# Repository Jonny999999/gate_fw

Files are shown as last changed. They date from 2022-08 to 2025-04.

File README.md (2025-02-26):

Custom pcb-design and firmware for an esp32 controlling a self-made automated sliding gate.  
Full Documentation: https://pfusch.zone/automated-sliding-gate

# Changelog V2.0
- Replace old multipurpose board with a custom pcb for controlling the gate
- custom pcb:
  - fully isolate microcontroller from long cables and VFD noise
  - RS485 interface
  - Servo interface to lock the gate
  - Preparation for Encoders
- control motors with VFDs instead of Relays
- firmware rework or rewrite

<br>

## pcb v2.0-isolated-gate-control
- **[KiCad Project](pcb_v2.0-isolated-gate-control/)**
- **[Schematic.pdf](pcb_v2.0-isolated-gate-control/export/schematic.pdf)**
- **[G-code for Isolation Milling](pcb_v2.0-isolated-gate-control/pcb2gcode)**  
  
- **[Connection plan](doc/V2.0_connection-plan.drawio.pdf)**

Schematic + layout preview:  
<p align="center">
  <a href="pcb_v2.0-isolated-gate-control/export/schematic.pdf">
    Schematic
  </a>
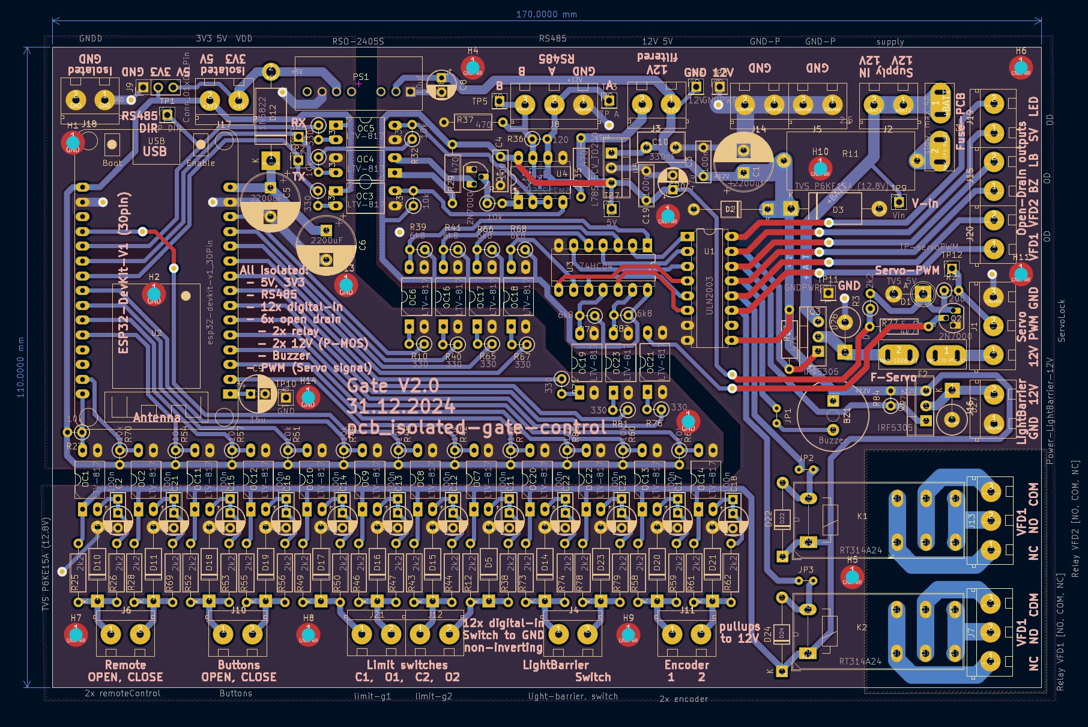
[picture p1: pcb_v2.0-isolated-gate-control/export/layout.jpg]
PCB Layout
  
</p>

<br>

## Photos
Photos of the V2.0 hardware setup (new custom made pcb, control cabinet and additional box with outsourced power supply and VFDs)
<p align="center">
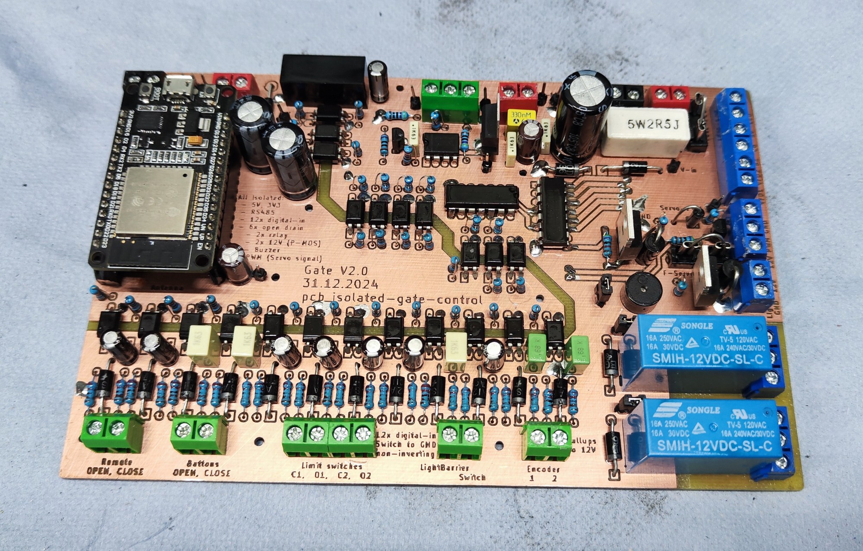
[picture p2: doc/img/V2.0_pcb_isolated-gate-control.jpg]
  
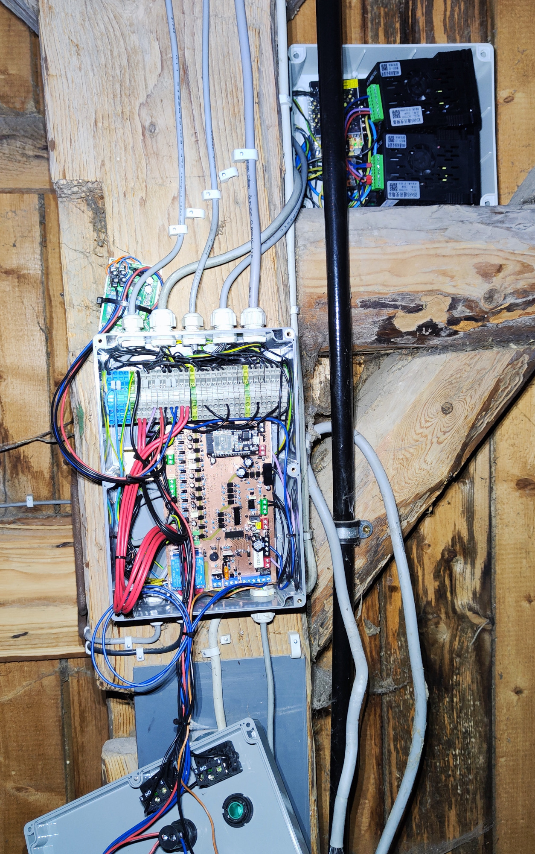
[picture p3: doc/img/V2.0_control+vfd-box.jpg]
  
</p>

<br>

# Installation
### Install esp-idf
For this project **ESP-IDF v5.3** is required  
(with other versions it most likely will not compile)
```bash
#download esp-idf (verify version!)
yay -S esp-idf #alternatively clone the esp-idf repository from github
#run installation script in installed folder
/opt/esp-idf/install.sh
```
### Clone this repo
```
git clone git@github.com:Jonny999999/gate_fw.git
```

# Compilation
### Set up environment
```bash
source /opt/esp-idf/export.sh
```
(run once in terminal)

### Compile
```bash
idf.py build
```

### Upload
**Important:** Since V2.0 the **east Gate has to be slightly open for the upload to work**  
(Since the gpio used for limit switch fully closed has to be pulled low during flashing)
- connect micro-usb cable to ESP32 module on pcb
- press REST and BOOT button
- release RESET button (keep pressing boot)
- run flash command:
```bash
idf.py flash
```
- once "connecting...' successfully, BOOT button can be released  

# Usage
See [function diagram](function-diagram.drawio.pdf) for a detailed overview of the implemented control.

### Open slightly
- press open button once -> opens for ~1s

### Open more
- press open button several times with less than 1s gap  
  -> opens 1s + 0.4s * times-pressed

### Open completely
- press open button for more than 0.8s
or
- press 'A-Button' on remote once

### Close completely
- press close button once  
  or
- press 'B-Button' on remote once

### Stop moving gate
- press any button (on gate or remote) while a gate moves  
Note: within 1s after pressing open button only close button or remote works to stop the gates

<br>

---

# Legacy -  Old Version V1.0
Left: Photo of control-pcb + RC-module (V1.0)  
Right: Photo of cabinet with power relays and V0.1 board (in V1.0 new board version was used and outsourced due to EMV issues when switching)
<p align="center">
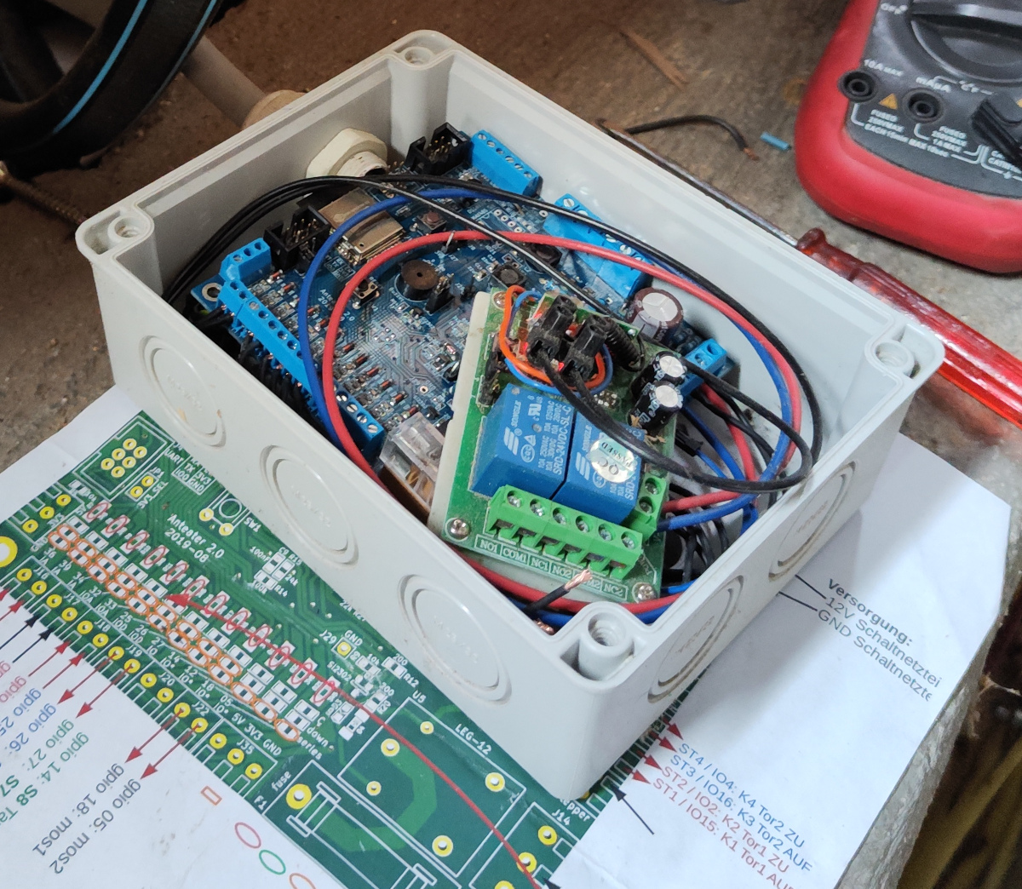
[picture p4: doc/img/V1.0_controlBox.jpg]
  
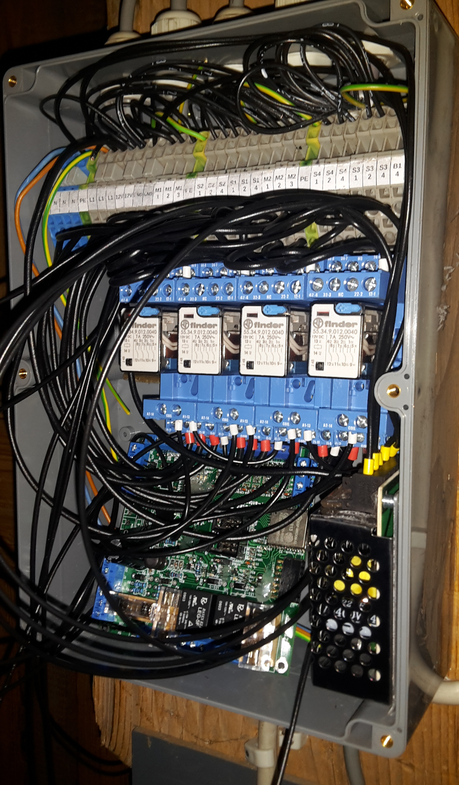
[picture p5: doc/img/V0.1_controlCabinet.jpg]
  
</p>

# Schema
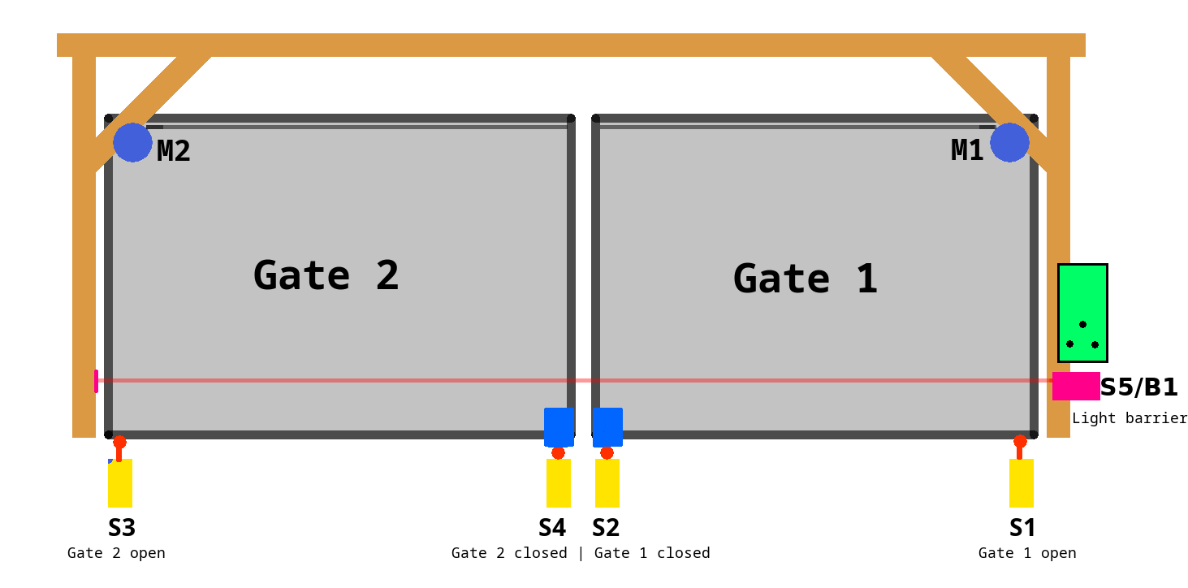
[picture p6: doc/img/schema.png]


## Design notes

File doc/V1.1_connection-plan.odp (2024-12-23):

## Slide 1

gpio 26: S4 Tor 2 zu

gpio 36:

gpio 39:

gpio 32: S1 Tor 1 offen

gpio 33: S2 Tor 1 zu

gpio 25: S3 Tor 2 offen

`

`

`

`

`

`

`

gpio 34:

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
gpio 27: S7 Taster AUF

`

gpio 14: S8 Taster ZU

gpio 05: mos2

gpio 18: mos1

`

`

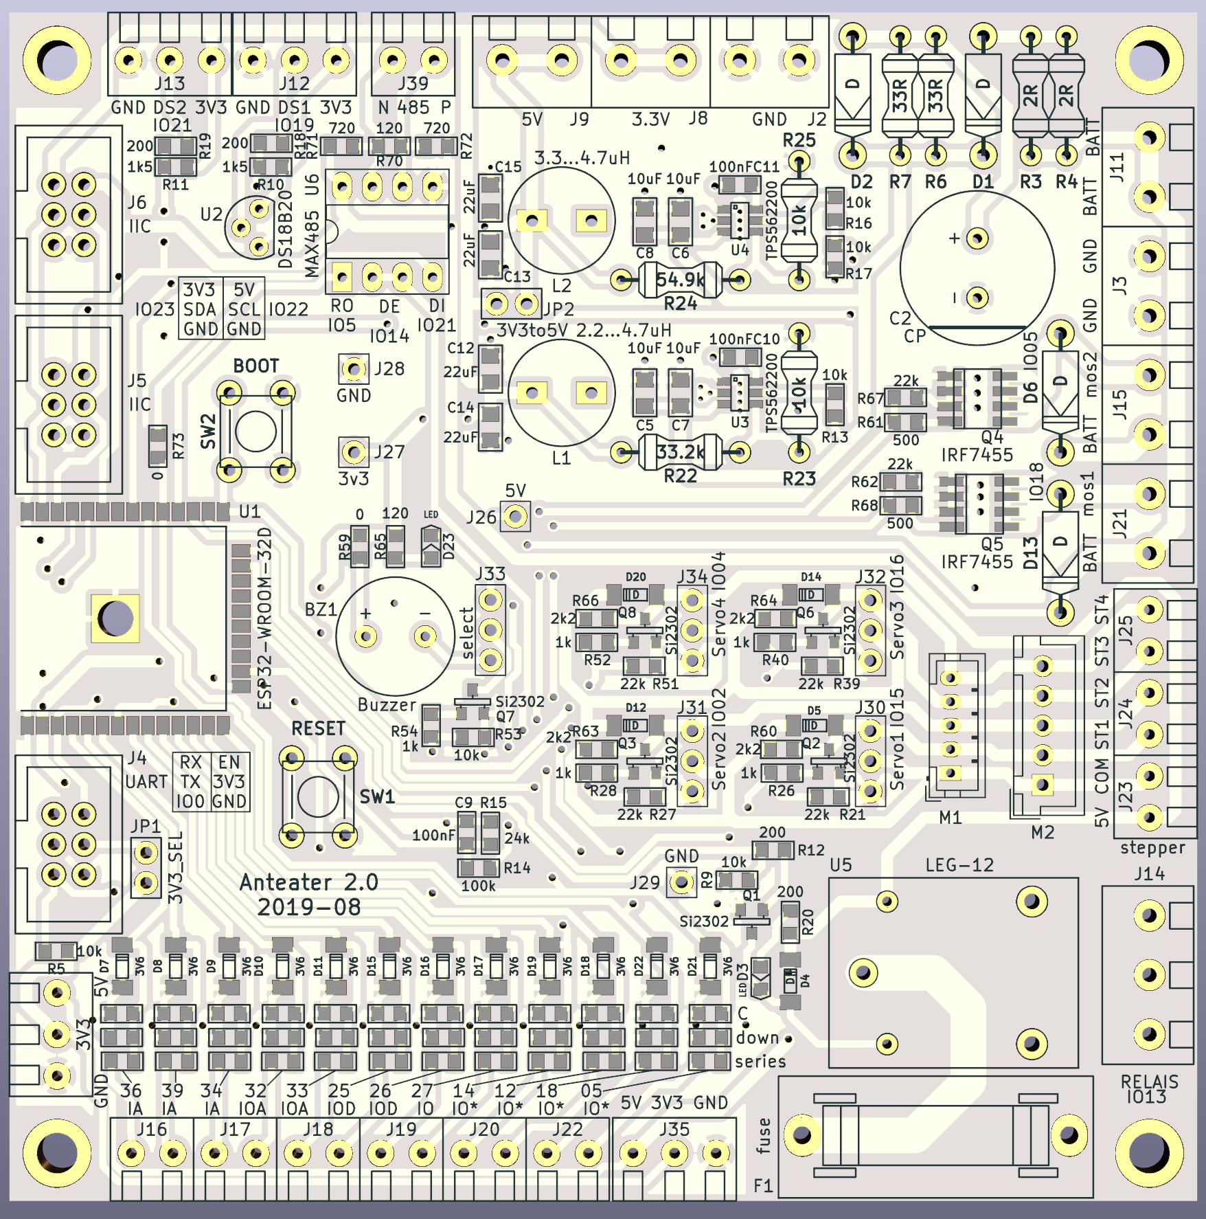
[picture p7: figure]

Supply:

12V

GND

(https://www.youtube.com/) (https://www.youtube.com/) (https://www.youtube.com/) (https://www.youtube.com/) (https://www.youtube.com/) (https://www.youtube.com/) (https://www.youtube.com/) (https://www.youtube.com/) (https://www.youtube.com/) (https://www.youtube.com/) DE (https://www.youtube.com/) (https://www.youtube.com/) (https://www.youtube.com/) (https://www.youtube.com/) (https://www.youtube.com/) (https://www.youtube.com/) (https://www.youtube.com/) (https://www.youtube.com/) (https://www.youtube.com/) (https://www.youtube.com/) (https://www.youtube.com/) (https://www.youtube.com/) (https://www.youtube.com/feed/trending) (https://www.youtube.com/feed/trending) (https://www.youtube.com/feed/subscriptions) (https://www.youtube.com/feed/subscriptions) (https://www.youtube.com/feed/library) (https://www.youtube.com/feed/library) (https://www.youtube.com/feed/library) (https://www.youtube.com/feed/history) (https://www.youtube.com/feed/history) (https://www.youtube.com/feed/my_videos) (https://www.youtube.com/feed/my_videos) (https://www.youtube.com/playlist?list=WL) (https://www.youtube.com/playlist?list=WL) (https://www.youtube.com/playlist?list=PLQ8QHWliGPtXNgohxmhCzfx_ddYAmVRxC) (https://www.youtube.com/playlist?list=PLQ8QHWliGPtXNgohxmhCzfx_ddYAmVRxC)

(https://www.youtube.com/channel/UCrQCutWhY0eJNmARDwkoQgQ) (https://www.youtube.com/channel/UC67gfx2Fg7K2NSHqoENVgwA) (https://www.youtube.com/channel/UCSE6yilNScIz1SLTNQvrXMw) (https://www.youtube.com/channel/UC2rzsm1Qi6N1X-wuOg_p0Ng) (https://www.youtube.com/channel/UCJ0-OtVpF0wOKEqT2Z1HEtA) (https://www.youtube.com/channel/UCOJe7abm8byWMR3JUeWk8BQ) (https://www.youtube.com/channel/UCizZsr6YKuhSK9sct4U9KXQ)

(https://www.youtube.com/premium) (https://www.youtube.com/premium) (https://www.youtube.com/feed/storefront?bp=ogUCKAI%3D) (https://www.youtube.com/feed/storefront?bp=ogUCKAI%3D) (https://www.youtube.com/feed/storefront?bp=ogUCKAI%3D) (https://www.youtube.com/gaming) (https://www.youtube.com/gaming) (https://www.youtube.com/channel/UC4R8DWoMoI7CAwX8_LjQHig) (https://www.youtube.com/channel/UC4R8DWoMoI7CAwX8_LjQHig) (https://www.youtube.com/channel/UC4R8DWoMoI7CAwX8_LjQHig) (https://www.youtube.com/channel/UCtFRv9O2AHqOZjjynzrv-xg) (https://www.youtube.com/channel/UCtFRv9O2AHqOZjjynzrv-xg) (https://www.youtube.com/account) (https://www.youtube.com/account) (https://www.youtube.com/reporthistory) (https://www.youtube.com/reporthistory) (https://www.youtube.com/yt/about/) (https://www.youtube.com/yt/press/) (https://www.youtube.com/yt/copyright/) (https://www.youtube.com/t/contact_us) (https://www.youtube.com/yt/creators/) (https://www.youtube.com/yt/advertise/) (https://www.youtube.com/yt/dev/) (https://www.youtube.com/t/impressum?hl=de&gl=DE) (https://transparencyreport.google.com/netzdg/youtube) (https://support.google.com/youtube/contact/netzdg) (https://www.youtube.com/t/terms) (https://www.google.com/intl/en/policies/privacy/) (https://www.youtube.com/yt/policyandsafety/) (https://www.youtube.com/new)

ST4 / IO4: K4 Tor2 ZU
ST3 / IO16: K3 Tor2 AUF
ST2 / IO2: K2 Tor1 ZU
ST1 / IO15: K1 Tor1 AUF

Voltage divider
R Values:

10k Ohm

0 Ohm
20k Ohm
10k Ohm

Cable controlBox → Cabinet
1: 12V
2: GND

3: K4 (Tor 2 zu)

4: K3 (Tor 2 auf)

5: K2 (Tor 1 zu)

6: K1 (Tor 1 auf)

7: B1 (Lichtschranke)

8: Reserve

9: S7 (Taster AUF)

10: S8 (Taster ZU)

11: S4 (Tor 2 geschlossen)

12: S3 (Tor 2 offen)

13: S2 (Tor 1 geschlossen)

14: S1 (Tor 1 offen)

Z Diodes 2,6 – 2,7V

Cable Button:
1: Common
2: NC

3: Free

4: NO

conflicting components:
gpio 05 VS mos2
gpio 18 VS mos1
gpio 12 VS LED/Buzzer
gpio 14 VS RS485

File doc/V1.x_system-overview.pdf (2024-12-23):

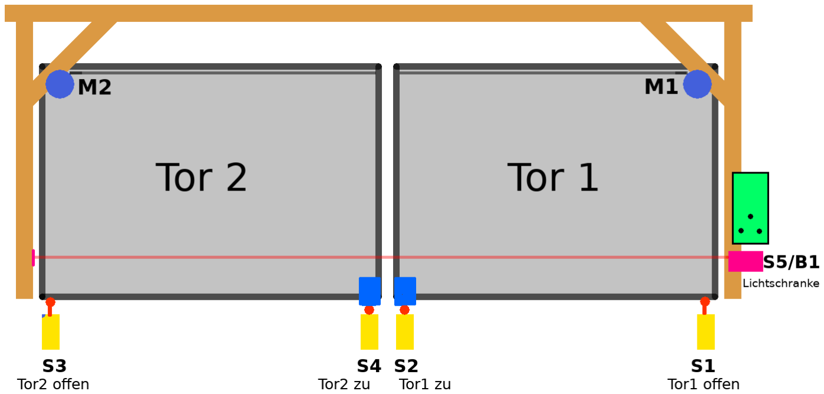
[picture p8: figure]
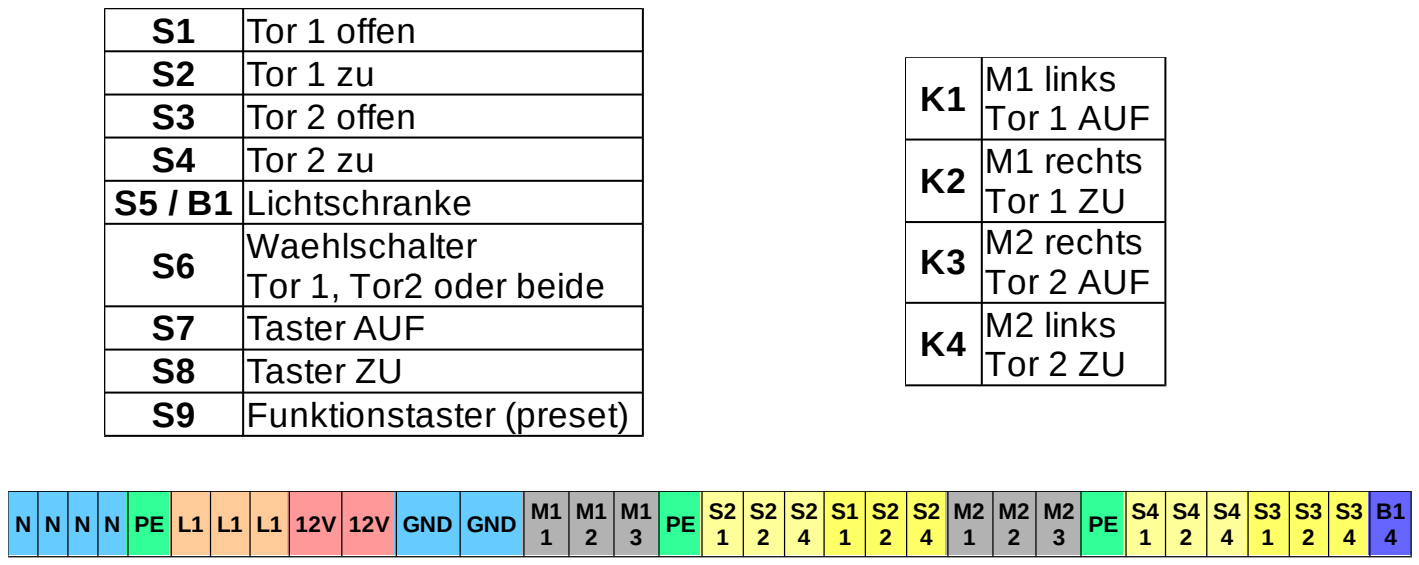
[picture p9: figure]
Tor 1 offen; Tor 1 zu; Tor 2 offen; Tor 2 zu; S5 / B1 Lichtschranke; Taster AUF; Taster ZU; Funktionstaster (preset); Waehlschalter Tor 1, Tor2 oder beide; M1 links Tor 1 AUF M1 rechts Tor 1 ZU M2 rechts Tor 2 AUF M2 links Tor 2 ZU; GND GND

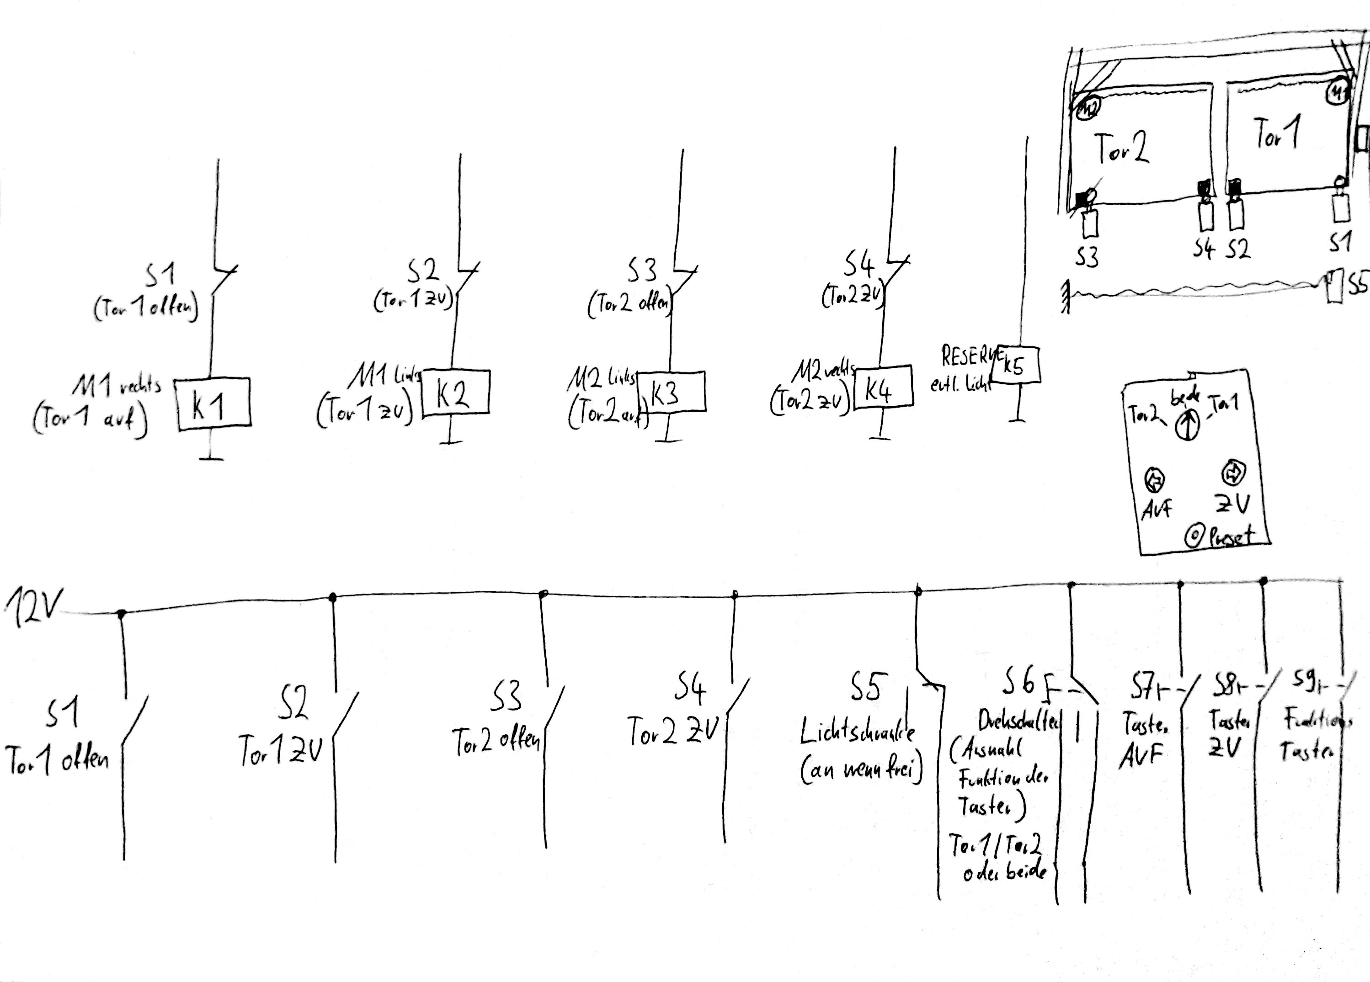
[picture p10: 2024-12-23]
doc/V1.0_schematic-cabinet.jpg

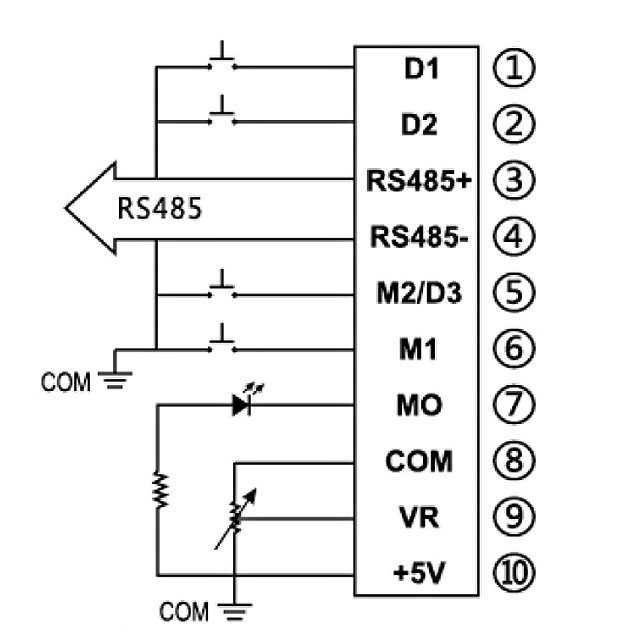
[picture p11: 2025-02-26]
doc/vfd/T13-400W-12-HT13-750W-12H-2.jpg

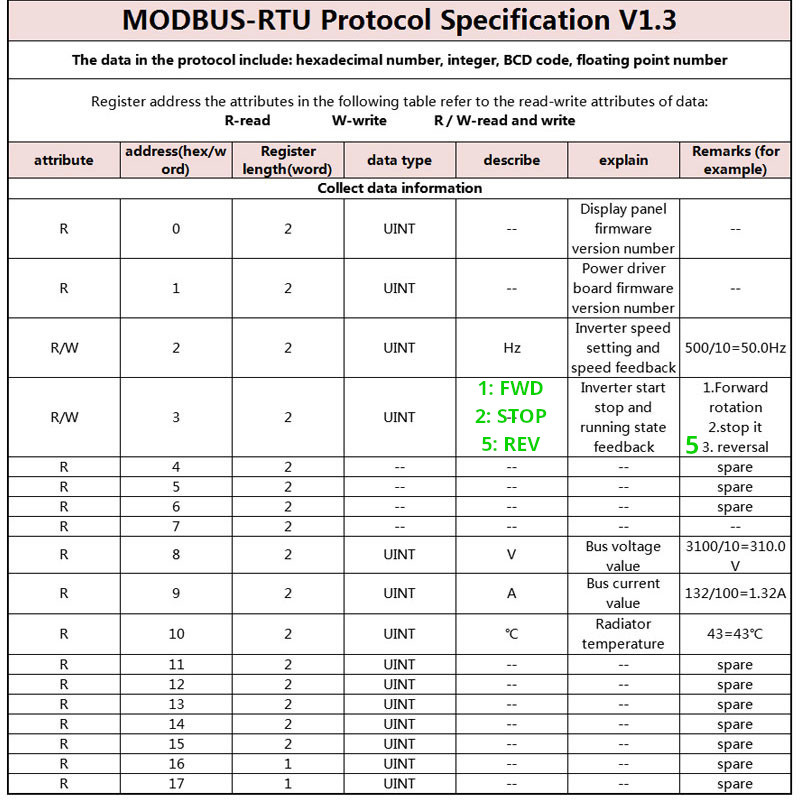
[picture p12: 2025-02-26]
doc/vfd/T13-400W-12-HT13-750W-12H_modbus.jpg

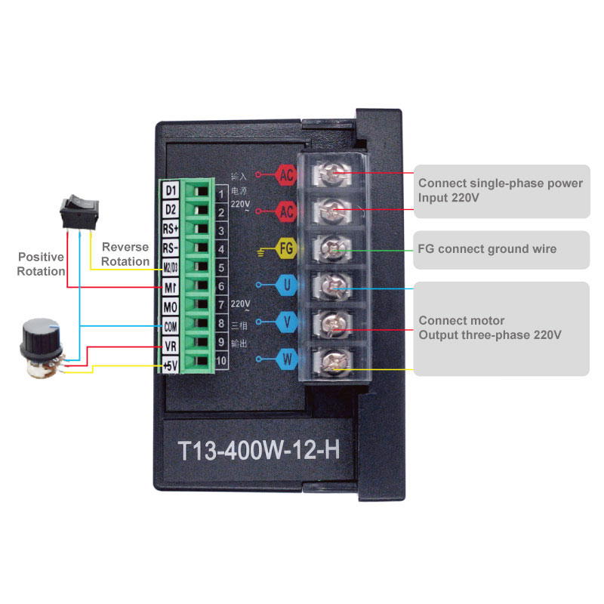
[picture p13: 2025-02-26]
doc/vfd/T13-400W-12-HT13-750W-12H-1.jpg

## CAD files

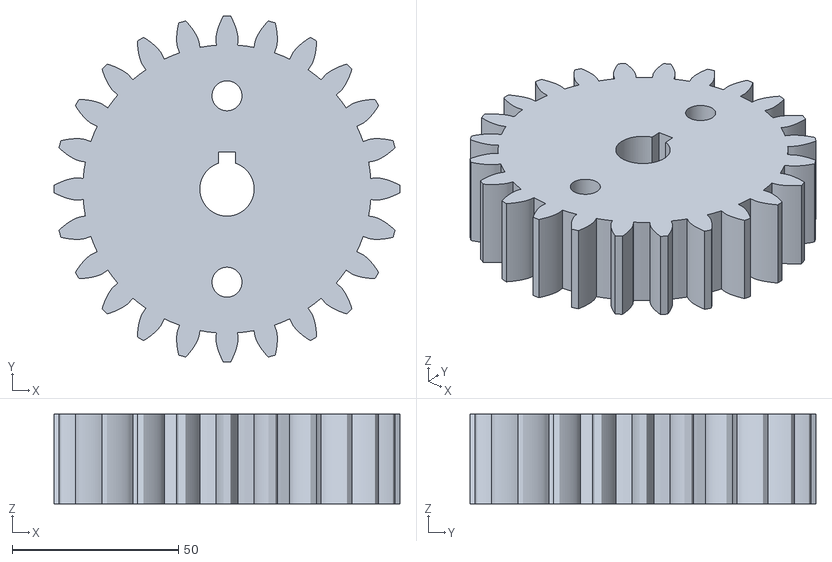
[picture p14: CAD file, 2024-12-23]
cad/spur-gear_m4_z24-v4.stl
104.0 x 104.0 x 27.0

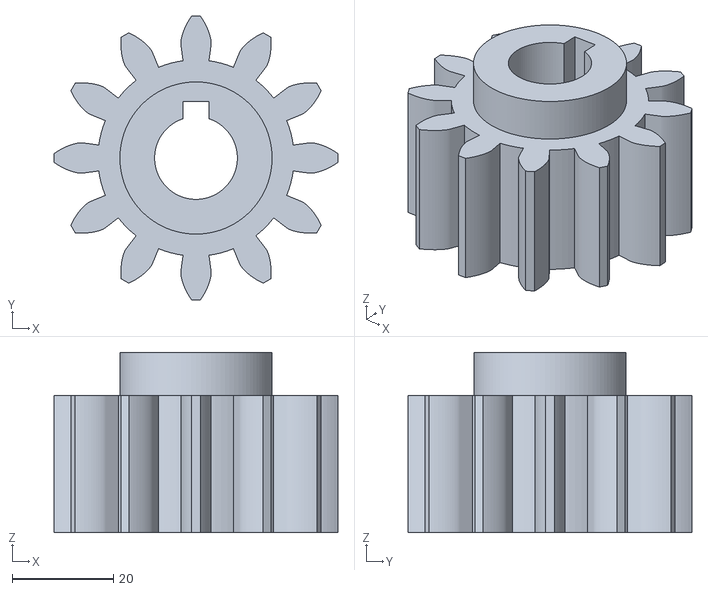
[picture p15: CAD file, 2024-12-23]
cad/spur-gear_m4_z12-v3.stl
56.0 x 56.0 x 35.5

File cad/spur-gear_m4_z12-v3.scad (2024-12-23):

// Spiel zwischen Zahnflanken
spiel = 0.1;


// Höhe des Zahnkopfes über dem Teilkreis
modul=4;


// Anzahl der Radzähne
zahnzahl=12;


// Zahnbreite default:10
// komplett bis motor breite=29+6.5;
breite=27;

// Durchmesser der Mittelbohrung 
bohrung=16.3;


// Eingriffswinkel, Standardwert = 20° gemäß DIN 867
eingriffswinkel=20;


// Schrägungswinkel zur Rotationsachse; 0° = Geradverzahnung default:15
schraegungswinkel=0;


// Löcher zur Material-/Gewichtsersparnis bzw. Oberflächenvergößerung erzeugen, wenn Geometrie erlaubt
optimiert = 0;


/* Bibliothek für Evolventen-Zahnräder für Thingiverse Customizer

Enthält die Module
stirnrad(modul, zahnzahl, breite, bohrung, eingriffswinkel = 20, schraegungswinkel = 0, optimiert = true)

Autor:		Dr Jörg Janssen
Stand:		6. Januar 2017
Version:	2.0
Lizenz:		Creative Commons - Attribution, Non Commercial, Share Alike

Erlaubte Module nach DIN 780:
0.05 0.06 0.08 0.10 0.12 0.16
0.20 0.25 0.3  0.4  0.5  0.6
0.7  0.8  0.9  1    1.25 1.5
2    2.5  3    4    5    6
8    10   12   16   20   25
32   40   50   60

*/


/* [Hidden] */
pi = 3.14159;
rad = 57.29578;
$fn = 96;

/*	Wandelt Radian in Grad um */
function grad(eingriffswinkel) =  eingriffswinkel*rad;

/*	Wandelt Grad in Radian um */
function radian(eingriffswinkel) = eingriffswinkel/rad;

/*	Wandelt 2D-Polarkoordinaten in kartesische um
    Format: radius, phi; phi = Winkel zur x-Achse auf xy-Ebene */
function pol_zu_kart(polvect) = [
	polvect[0]*cos(polvect[1]),  
	polvect[0]*sin(polvect[1])
];

/*	Kreisevolventen-Funktion:
    Gibt die Polarkoordinaten einer Kreisevolvente aus
    r = Radius des Grundkreises
    rho = Abrollwinkel in Grad */
function ev(r,rho) = [
	r/cos(rho),
	grad(tan(rho)-radian(rho))
];

/*  Wandelt Kugelkoordinaten in kartesische um
    Format: radius, theta, phi; theta = Winkel zu z-Achse, phi = Winkel zur x-Achse auf xy-Ebene */
function kugel_zu_kart(vect) = [
	vect[0]*sin(vect[1])*cos(vect[2]),  
	vect[0]*sin(vect[1])*sin(vect[2]),
	vect[0]*cos(vect[1])
];


/*  Stirnrad
    modul = Höhe des Zahnkopfes über dem Teilkreis
    zahnzahl = Anzahl der Radzähne
    breite = Zahnbreite
    bohrung = Durchmesser der Mittelbohrung
    eingriffswinkel = Eingriffswinkel, Standardwert = 20° gemäß DIN 867. Sollte nicht größer als 45° sein.
    schraegungswinkel = Schrägungswinkel zur Rotationsachse; 0° = Geradverzahnung
	optimiert = Löcher zur Material-/Gewichtsersparnis bzw. Oberflächenvergößerung erzeugen, wenn Geometrie erlaubt (= 1, wenn wahr) */
module stirnrad(modul, zahnzahl, breite, bohrung, eingriffswinkel = 20, schraegungswinkel = 0, optimiert = true) {

	// Dimensions-Berechnungen	
	d = modul * zahnzahl;											// Teilkreisdurchmesser
	r = d / 2;														// Teilkreisradius
	alpha_stirn = atan(tan(eingriffswinkel)/cos(schraegungswinkel));// Schrägungswinkel im Stirnschnitt
	db = d * cos(alpha_stirn);										// Grundkreisdurchmesser
	rb = db / 2;													// Grundkreisradius
	da = (modul <1)? d + modul * 2.2 : d + modul * 2;				// Kopfkreisdurchmesser nach DIN 58400 bzw. DIN 867
	ra = da / 2;													// Kopfkreisradius
	c =  (zahnzahl <3)? 0 : modul/6;								// Kopfspiel
	df = d - 2 * (modul + c);										// Fußkreisdurchmesser
	rf = df / 2;													// Fußkreisradius
	rho_ra = acos(rb/ra);											// maximaler Abrollwinkel;
																	// Evolvente beginnt auf Grundkreis und endet an Kopfkreis
	rho_r = acos(rb/r);												// Abrollwinkel am Teilkreis;
																	// Evolvente beginnt auf Grundkreis und endet an Kopfkreis
	phi_r = grad(tan(rho_r)-radian(rho_r));							// Winkel zum Punkt der Evolvente auf Teilkreis
	gamma = rad*breite/(r*tan(90-schraegungswinkel));				// Torsionswinkel für Extrusion
	schritt = rho_ra/16;											// Evolvente wird in 16 Stücke geteilt
	tau = 360/zahnzahl;												// Teilungswinkel
	
	r_loch = (2*rf - bohrung)/8;									// Radius der Löcher für Material-/Gewichtsersparnis
	rm = bohrung/2+2*r_loch;										// Abstand der Achsen der Löcher von der Hauptachse
	z_loch = floor(2*pi*rm/(3*r_loch));								// Anzahl der Löcher für Material-/Gewichtsersparnis
	
	optimiert = (optimiert && r >= breite*1.5 && d > 2*bohrung);	// ist Optimierung sinnvoll?

	// Zeichnung
	union(){
		rotate([0,0,-phi_r-90*(1-spiel)/zahnzahl]){						// Zahn auf x-Achse zentrieren;
																		// macht Ausrichtung mit anderen Rädern einfacher

			linear_extrude(height = breite, twist = gamma){
				difference(){
					union(){
						zahnbreite = (180*(1-spiel))/zahnzahl+2*phi_r;
						circle(rf);										// Fußkreis	
						for (rot = [0:tau:360]){
							rotate (rot){								// "Zahnzahl-mal" kopieren und drehen
								polygon(concat(							// Zahn
									[[0,0]],							// Zahnsegment beginnt und endet im Ursprung
									[for (rho = [0:schritt:rho_ra])		// von null Grad (Grundkreis)
																		// bis maximalen Evolventenwinkel (Kopfkreis)
										pol_zu_kart(ev(rb,rho))],		// Erste Evolventen-Flanke

									[pol_zu_kart(ev(rb,rho_ra))],		// Punkt der Evolvente auf Kopfkreis

									[for (rho = [rho_ra:-schritt:0])	// von maximalen Evolventenwinkel (Kopfkreis)
																		// bis null Grad (Grundkreis)
										pol_zu_kart([ev(rb,rho)[0], zahnbreite-ev(rb,rho)[1]])]
																		// Zweite Evolventen-Flanke
																		// (180*(1-spiel)) statt 180 Grad,
																		// um Spiel an den Flanken zu erlauben
									)
								);
							}
						}
					}			
					circle(r = rm+r_loch*1.49);							// "Bohrung"
				}
			}
		}
        
		// mit Materialersparnis
		if (optimiert) {
			linear_extrude(height = breite){
				difference(){
						circle(r = (bohrung+r_loch)/2);
						circle(r = bohrung/2);							// Bohrung
					}
				}
			linear_extrude(height = (breite-r_loch/2 < breite*2/3) ? breite*2/3 : breite-r_loch/2){
				difference(){
                 
					circle(r=rm+r_loch*1.51);
					union(){
						circle(r=(bohrung+r_loch)/2);
						for (i = [0:1:z_loch]){
							translate(kugel_zu_kart([rm,90,i*360/z_loch]))
								circle(r = r_loch);
						}
					}
				}
			}
		}
		// ohne Materialersparnis
		else {

			linear_extrude(height = breite){
				difference(){
					circle(r = rm+r_loch*1.51);
					circle(r = bohrung/2);
				}
			}
		}
	}
}



        //passfederbreite=5.25; (gut wackelt aber)
    passfederbreite=5.10;
    passfederueberstand=3;
    



%cylinder(d=85,h=10);
//cylinder(d=130,h=5);
difference(){
    
    stirnrad(modul, zahnzahl, breite, bohrung, eingriffswinkel, schraegungswinkel, optimiert);
    

    translate ([-passfederbreite/2, 0, -1])
       cube ([passfederbreite, bohrung/2+passfederueberstand, 50]);
    cylinder(d=26,h=6.5);
   
    
}




    translate ([0, 0, breite])
    difference(){
        cylinder(d=30,h=35.5-breite);
        cylinder(d=bohrung,h=35.5-breite+1);
        translate ([-passfederbreite/2, 0, -1])
            cube ([passfederbreite, bohrung/2+passfederueberstand, 50]);
    }
    
    
    
    
    
    
    
    
    
    
    
    
    
    
    
    
    
    
    
    
    
    
    
    
    
//%cylinder(h=10, d=100; center = true);

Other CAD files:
cad/spur-gear_m4_z24-v4.scad

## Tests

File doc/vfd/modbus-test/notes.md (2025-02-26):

## Connection Guide
FTDI USB Serial Device converter

connect terminals:
**VFD  <->  FTDI**
  COM  -> GND
  RS-  -> P
  RS+  -> A

## VFD 
run reverse direction value in documentation is wrong -> `5` worked
-> test other values if features do not work

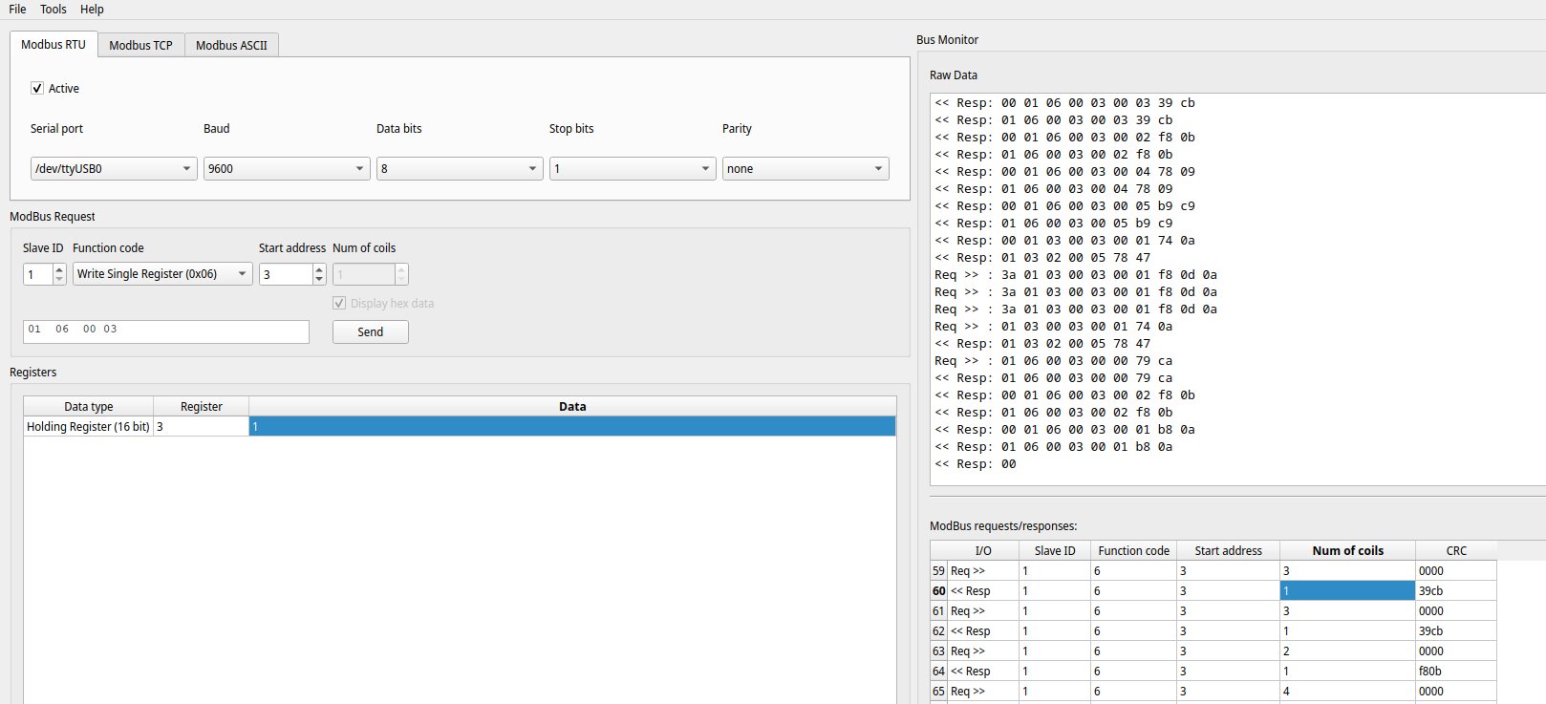
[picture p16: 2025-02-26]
doc/vfd/modbus-test/start.jpg

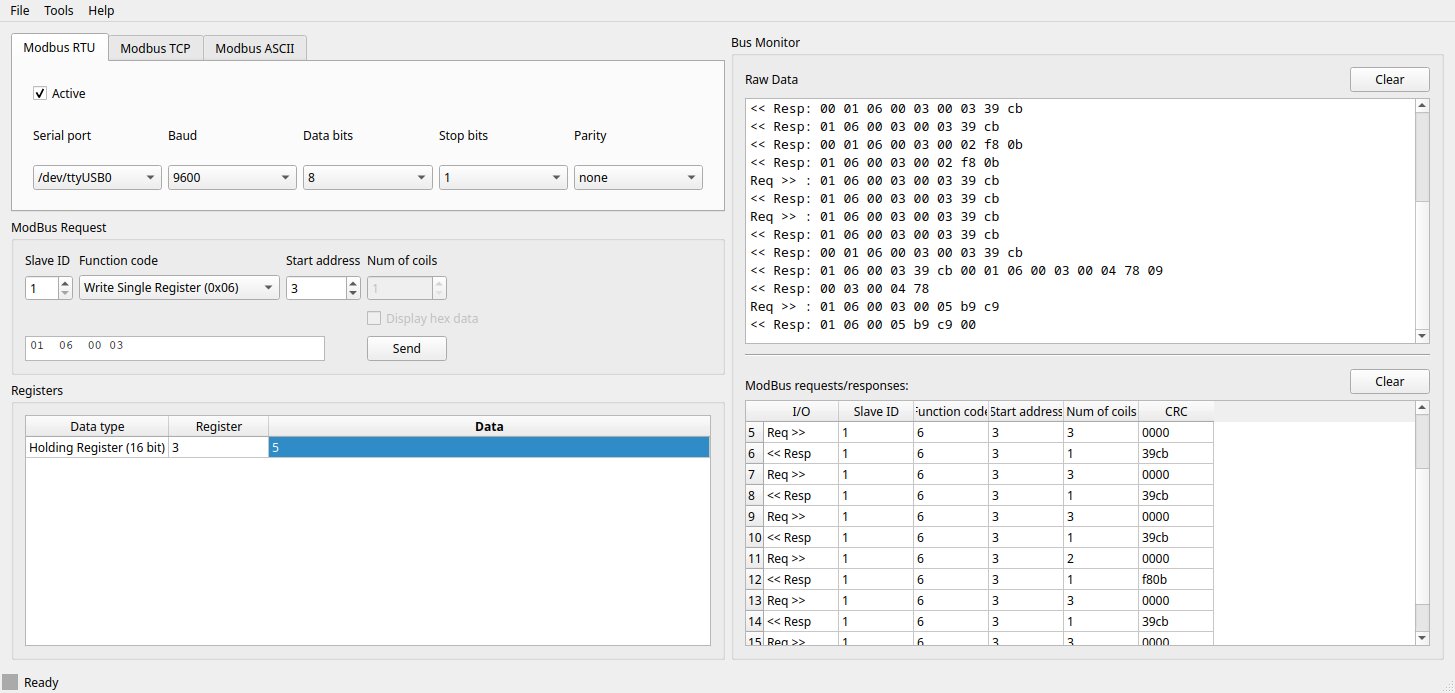
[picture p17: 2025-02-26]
doc/vfd/modbus-test/reverse.jpg

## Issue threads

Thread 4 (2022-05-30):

Functionality to switch log level

Jonny999999, 2022-05-30:
Ability to toggle between different loglevels.
## Ideas:
- when both buttons are pressed for 1s switch to other loglevel
- 3 options warn info debug?

```
    ESP_LOGE - error (lowest)
    ESP_LOGW - warning
    ESP_LOGI - info
    ESP_LOGD - debug
    ESP_LOGV - verbose (highest)
```

Jonny999999, 2025-08-21:
Idea dropped, just change level in code and re-flash for debugging.
not worth ir since its rarely needed...

Closed 2025-08-21.

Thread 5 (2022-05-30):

Weird behaivor when *both button pressed*

Jonny999999, 2022-05-30:
Handle case when both buttons are pressed at the same time.
Currently gates seemingly behave random in the first second (e.g right gate opens, left stays, gate changes direction...)

## notes
- difficult to handle
- buttons are never pressed exactly at the same time

Closed 2025-08-21.

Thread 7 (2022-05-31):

Control over network (MQTT, nodered, webinterface)

Jonny999999, 2022-05-31:
# evaluate the idea
Is it worth implementing the control via web interface considering the following?
- how often needed to control the gate with a phone?
  use cases:
  - car
    - (-) car hat parks there most of the time has remote attached to key
    - (+) other car might have to park there rarely (very useful!)
  - tractor
    - (-) tractor that parks there most of the time has remote next to seat
    - (+) other tractor needs to enter (rarely happens though)
  - person
    - (-) can simply press the button
  - computer
     - (+) could check and close the gate at the evening when forgotten

# Ideas
- get some kind of buttons on phone homescreen?
   - maybe issue with triggering it by accident?
   - direct link (http api)
- web interface like "water pump control"
- show / log statistics
  - how many times opened/closed

Closed 2025-08-21.

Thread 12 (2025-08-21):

Powersave:  turn off RS485 TX-EN (DIR) Signal in IDLE  (optocoupler off)

Jonny999999, 2025-08-21:
# Issue / idea

See note schematic:
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
Currently in idle (99.9% of the time) optocoupler for RS485 TX-EN is always on, but we will never receive anything without a request before

# Ideas
- Disable UART entirely when idle?
- Only switch to receive briefly after sending command for response?

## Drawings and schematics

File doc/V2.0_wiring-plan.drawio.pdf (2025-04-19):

## VFD-Box

### Motor

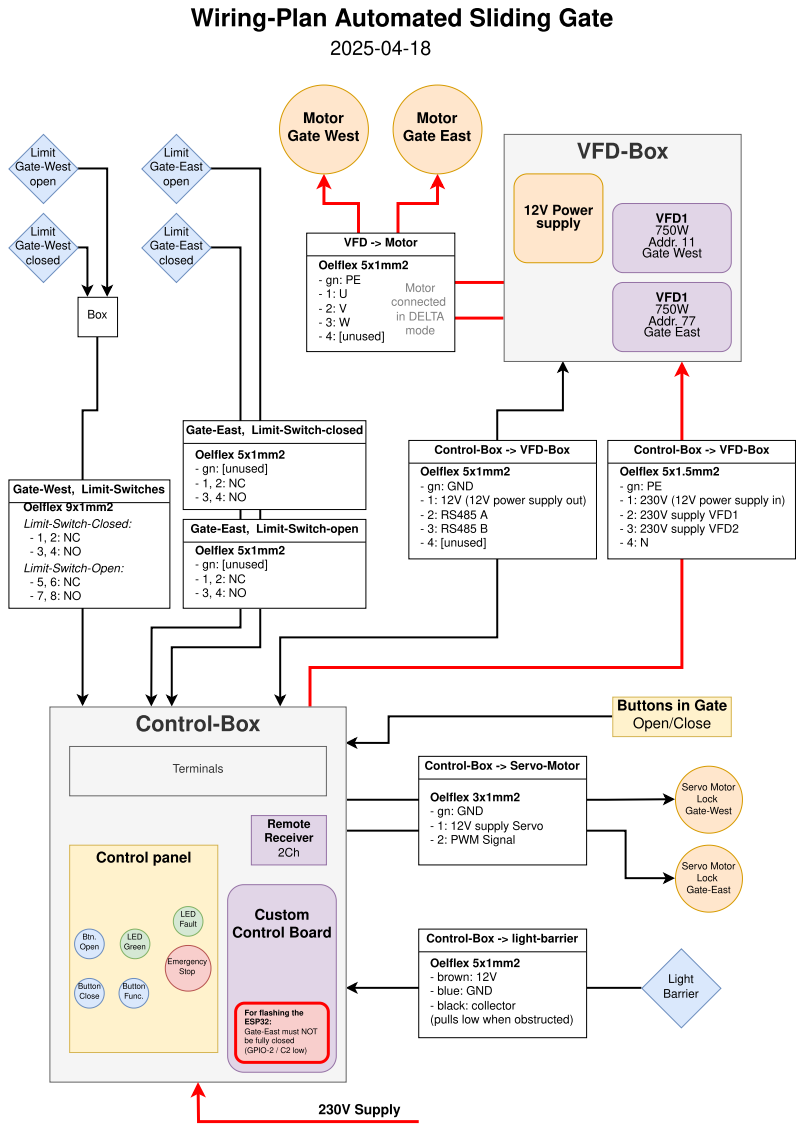
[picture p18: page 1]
Control-Box; Gate East; Oelflex 5x1mm2 - gn: [unused] - 1, 2: NC - 3, 4: NO; - 3: W - 4: [unused]; Motor; connected; in DELTA; mode; Motor Gate West; Limit Gate-East closed; Limit Gate-East open; Limit Gate-West closed; Limit Gate-West open; Light Barrier; Servo Motor Lock Gate-East; VFD1 750W Addr. 77 Gate East; VFD1 750W Addr. 11 Gate West; 12V Power supply; Custom Control Board; Terminals; Control panel; Emergency Stop; LED Fault; LED Green; Btn. Open; Button Close; Button Func.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

Wiring-Plan Automated Sliding Gate

VFD -> Motor

Oelflex 5x1mm2 - 1: U - 2: V

Gate-East, Limit-Switch-closed

Control-Box -> VFD-Box
Oelflex 5x1mm2
- gn: GND
- 1: 12V (12V power supply out)
- 4: [unused]

Oelflex 5x1.5mm2
- 1: 230V (12V power supply in)
- 2: 230V supply VFD1
- 3: 230V supply VFD2

Gate-West, | Limit-Switches
Oelflex 9x1mm2 Limit-Switch-Closed: - 1, 2: NC - 3, 4: NO Limit-Switch-Open: - 5, 6: NC - 7, 8: NO

Gate-East, Limit-Switch-open
Oelflex 5x1mm2 - gn: [unused] - 1, 2: NC - 3, 4: NO

Buttons in Gate
Open/Close

Control-Box -> Servo-Motor

- gn: GND - 1: 12V supply Servo

- 2: PWM Signal

Control-Box -> light-barrier

- brown: 12V
- blue: GND
- black: collector
(pulls low when obstructed)

For flashing the
ESP32:
Gate-East must NOT
be fully closed
(GPIO-2 / C2 low)

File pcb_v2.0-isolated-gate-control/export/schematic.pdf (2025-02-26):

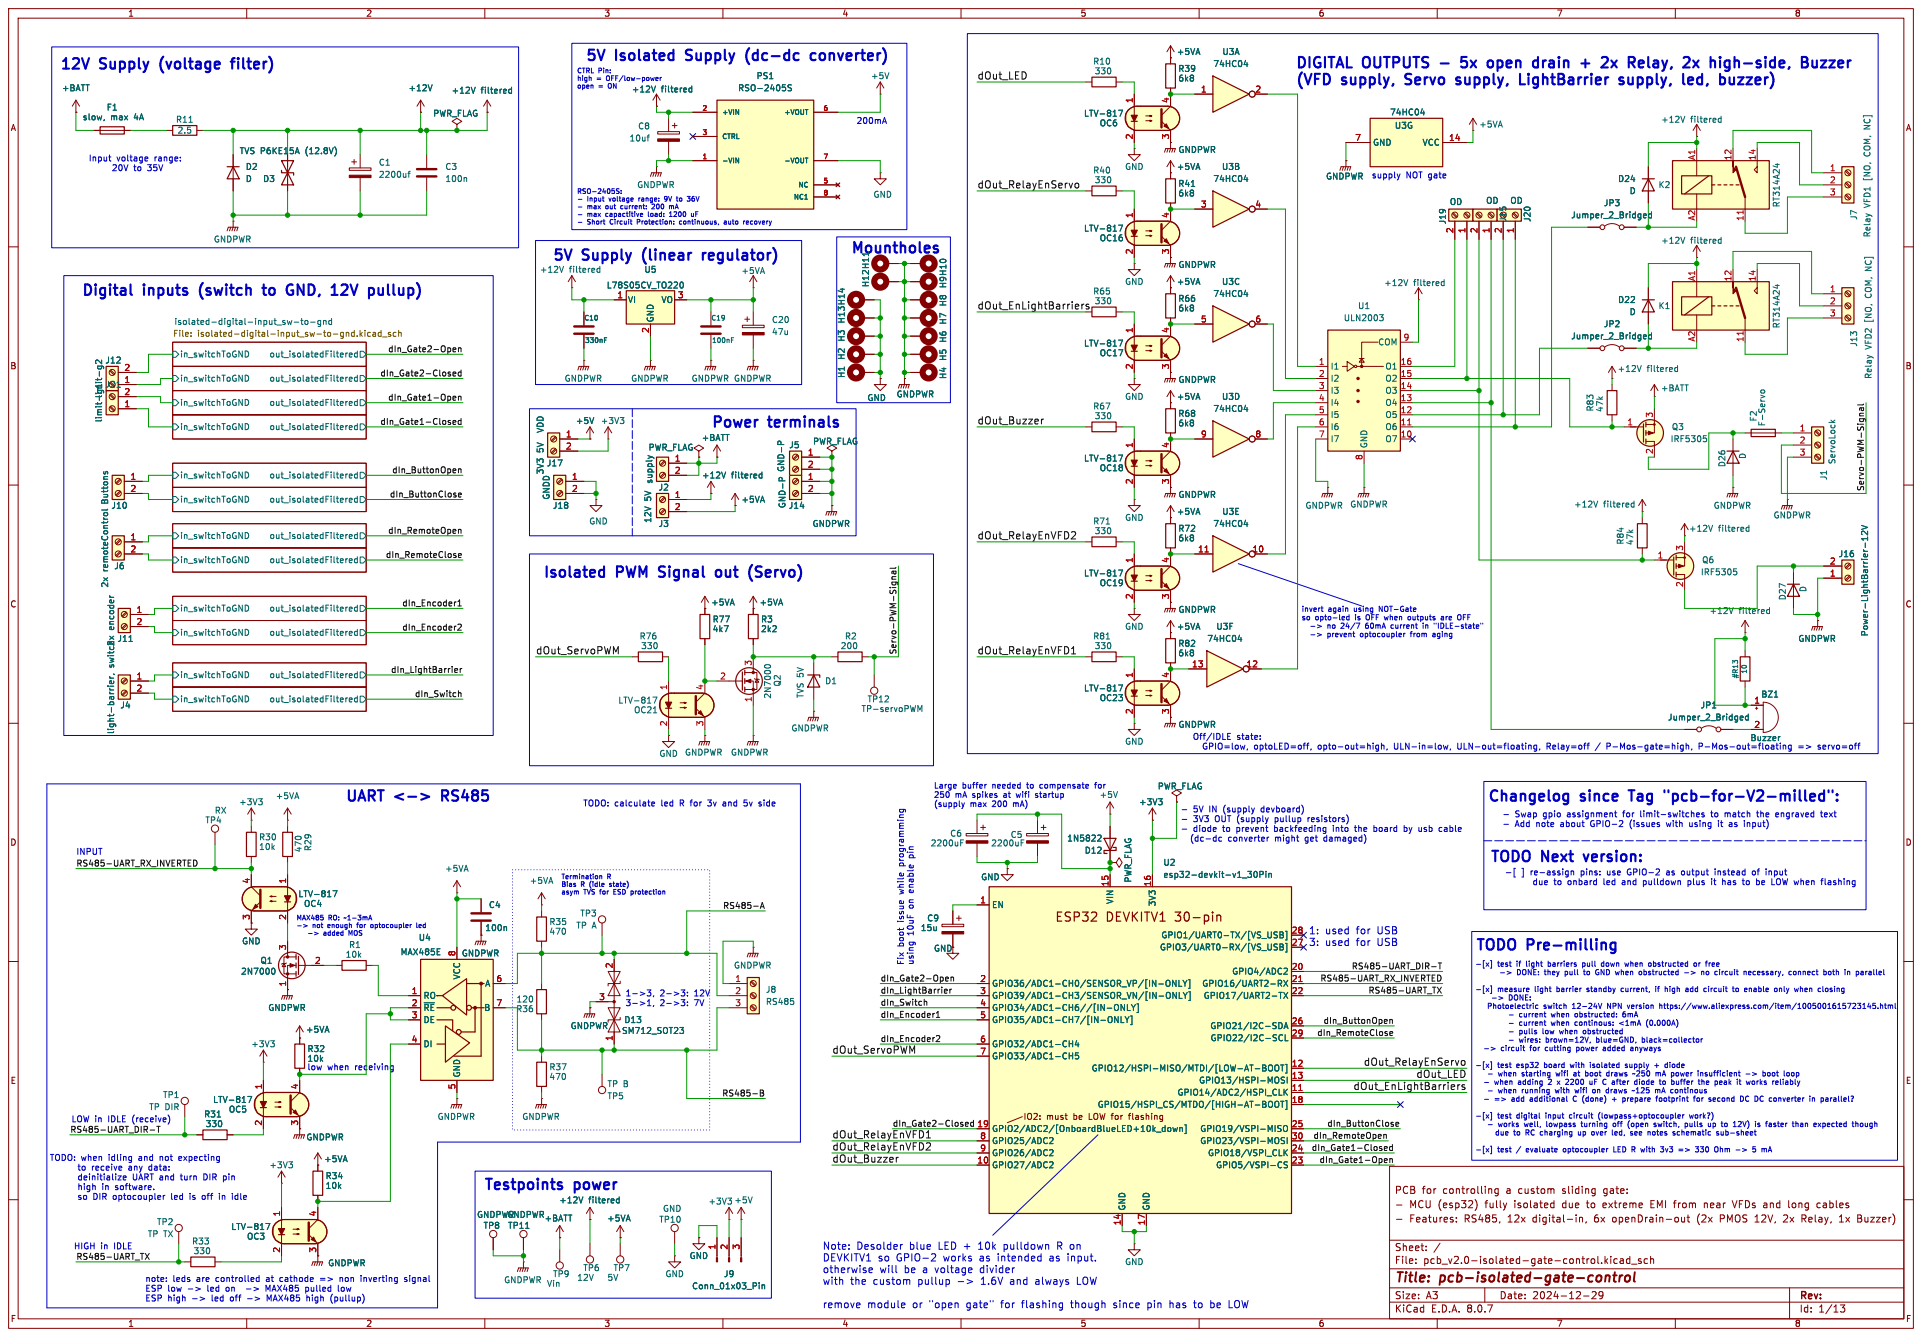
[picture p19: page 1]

CTRL Pin: high = OFF/low-power open = ON 12V Supply (voltage filter)

(VFD supply, Servo supply, LightBarrier supply, led, buzzer)

isolated-digital-input_sw-to-gnd File: isolated-digital-input_sw-to-gnd.kicad_sch

Isolated PWM Signal out (Servo)

dIn_Gate1-Closed Servo-PWM-Signal

invert again using NOT-Gate

- 5V IN (supply devboard)
- 3V3 OUT (supply pullup resistors)

- pulls low when obstructed

- when adding 2 x 2200 uF C after diode to buffer the peak it works reliably
- when running with wifi on draws ~125 mA continous

LOW in IDLE (receive)
RS485-UART_DIR-T

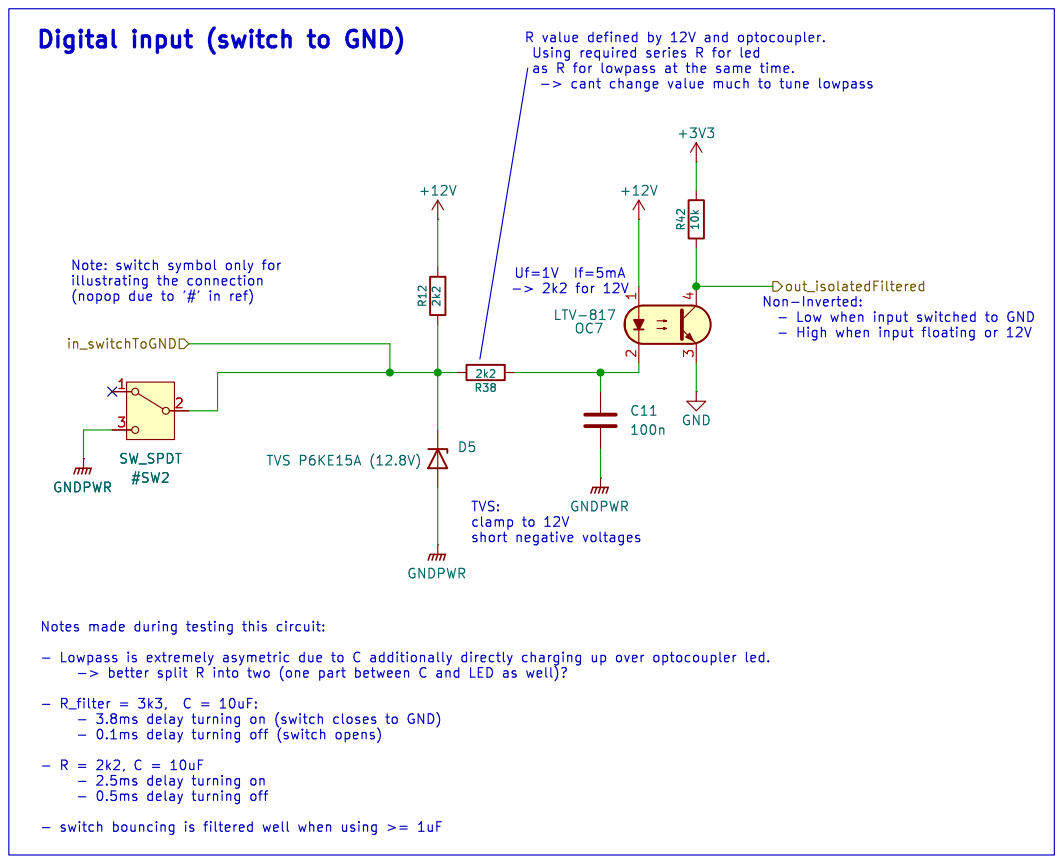
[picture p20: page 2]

(nopop due to '#' in ref) #SW2 SW_SPDT

- 0.1ms delay turning off (switch opens)

Id: 2/13 Title: File: isolated-digital-input_sw-to-gnd.kicad_sch Sheet: /isolated-digital-input_sw-to-gnd/

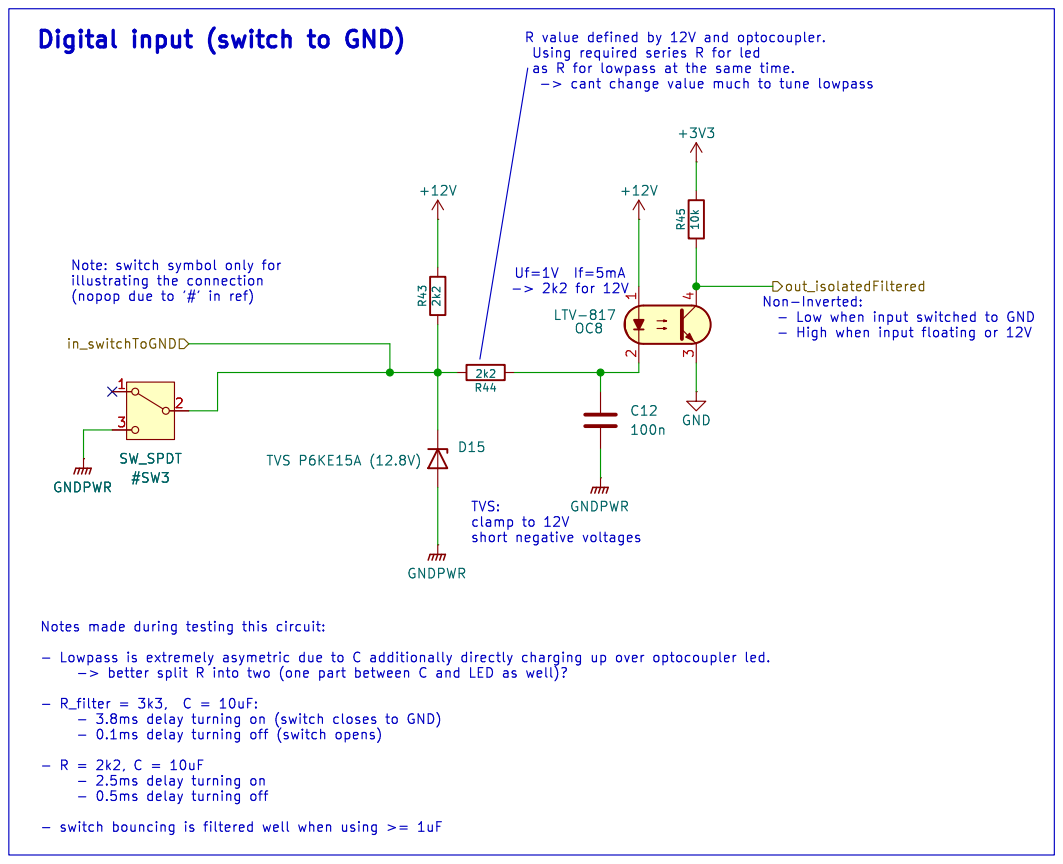
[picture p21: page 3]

Note: switch symbol only for

Id: 3/13 Title: File: isolated-digital-input_sw-to-gnd.kicad_sch Sheet: /isolated-digital-input_sw-to-gnd1/ GNDPWR GNDPWR

- 0.1ms delay turning off (switch opens)

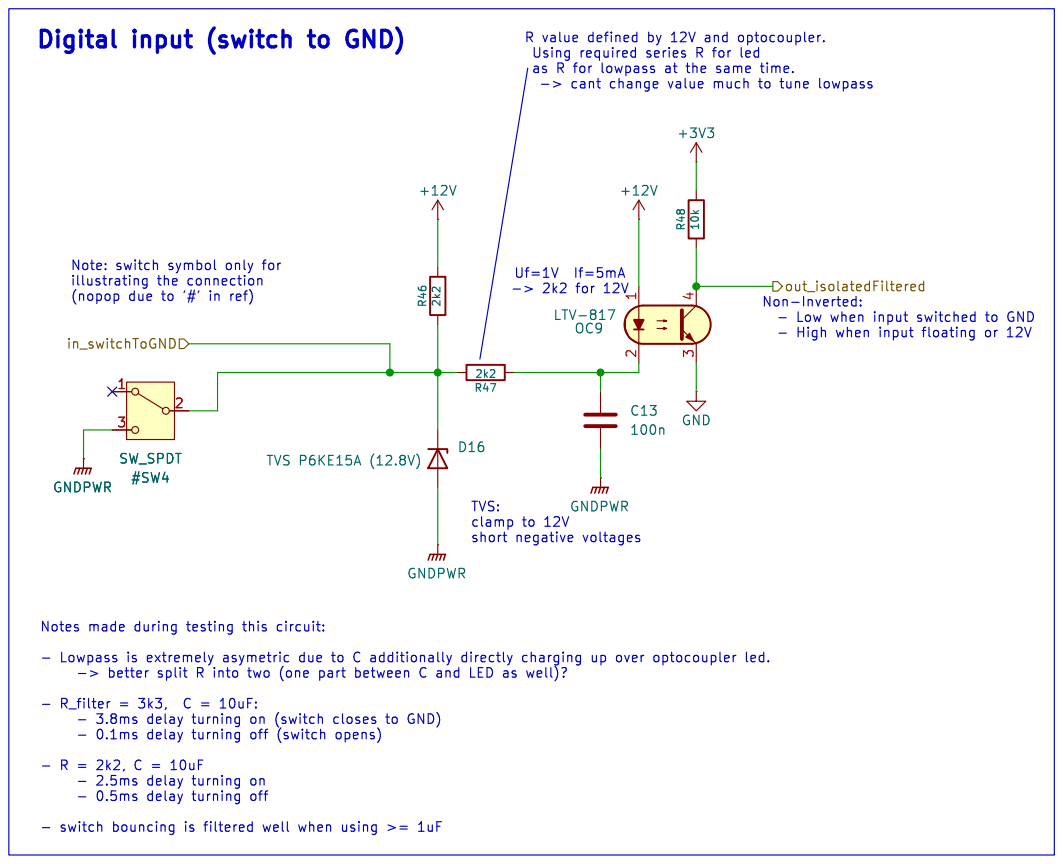
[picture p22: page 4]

Note: switch symbol only for

Id: 4/13 Title: File: isolated-digital-input_sw-to-gnd.kicad_sch Sheet: /isolated-digital-input_sw-to-gnd2/ GNDPWR GNDPWR

- 0.1ms delay turning off (switch opens)

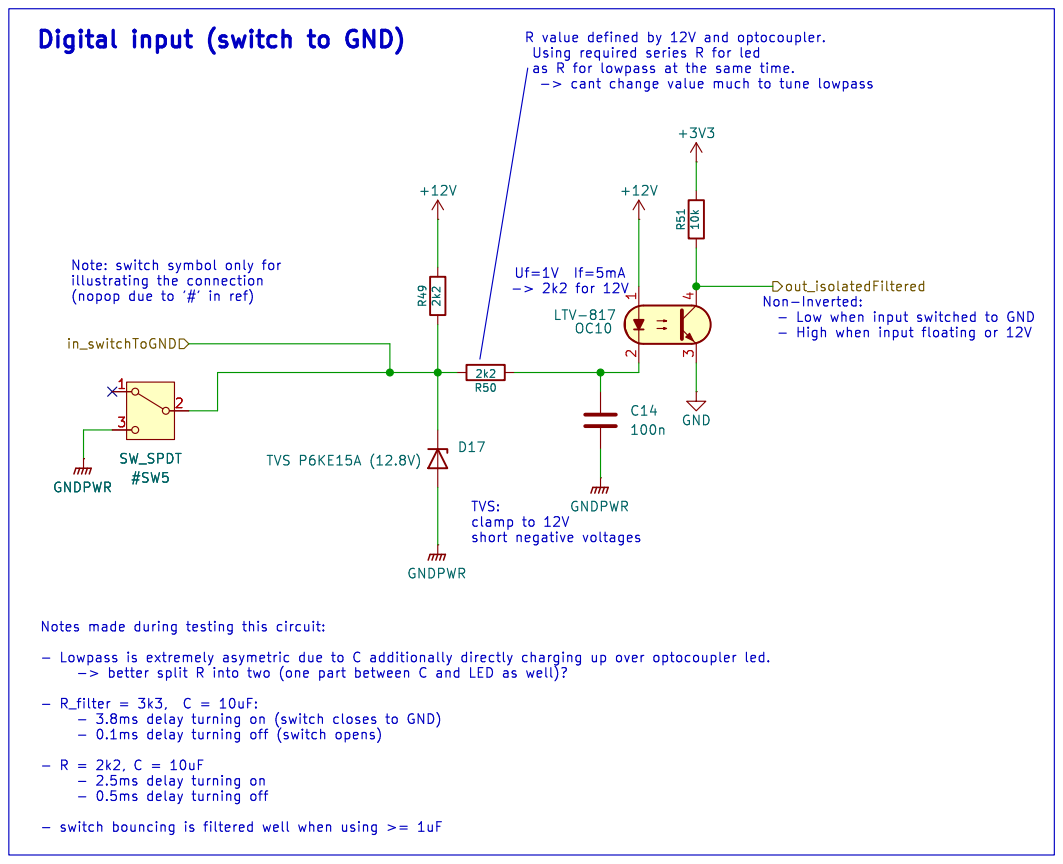
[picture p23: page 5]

Note: switch symbol only for

Id: 5/13 Title: File: isolated-digital-input_sw-to-gnd.kicad_sch Sheet: /isolated-digital-input_sw-to-gnd3/ GNDPWR GNDPWR

- 0.1ms delay turning off (switch opens)

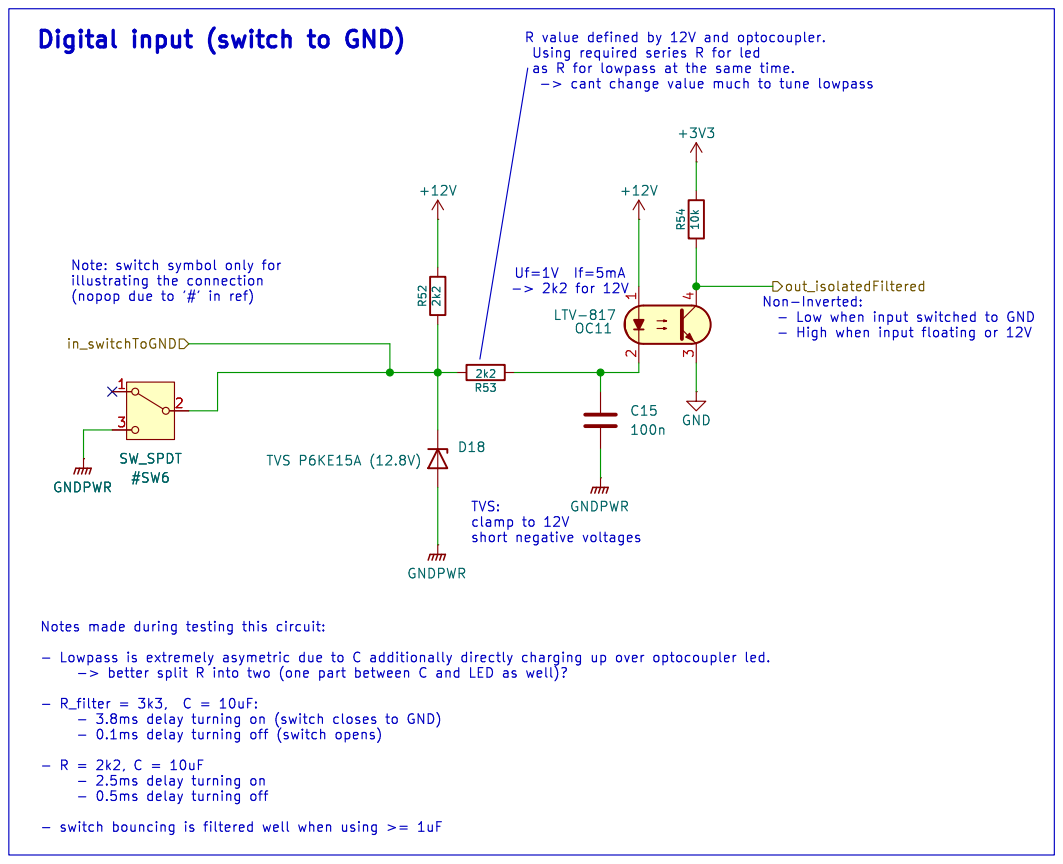
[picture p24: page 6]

Note: switch symbol only for

Id: 6/13 Title: File: isolated-digital-input_sw-to-gnd.kicad_sch Sheet: /isolated-digital-input_sw-to-gnd4/ GNDPWR GNDPWR

- 0.1ms delay turning off (switch opens)

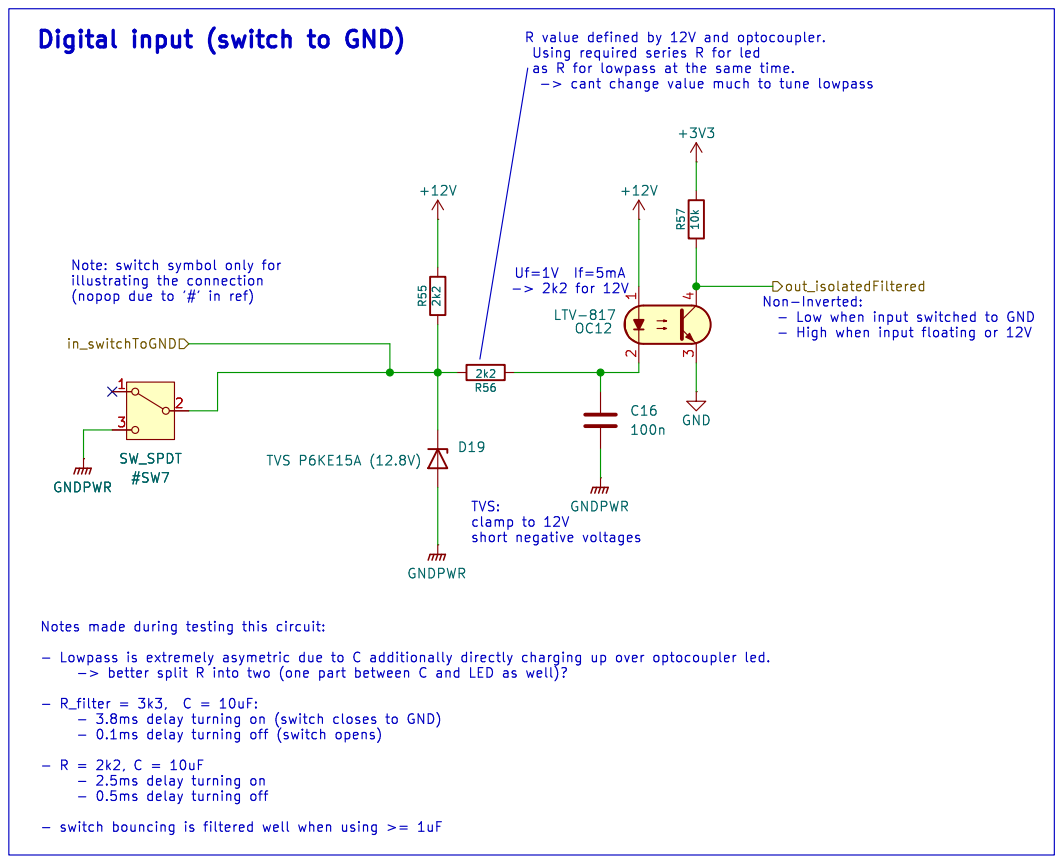
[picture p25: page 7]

Note: switch symbol only for

Id: 7/13 Title: File: isolated-digital-input_sw-to-gnd.kicad_sch Sheet: /isolated-digital-input_sw-to-gnd5/ GNDPWR GNDPWR

- 0.1ms delay turning off (switch opens)

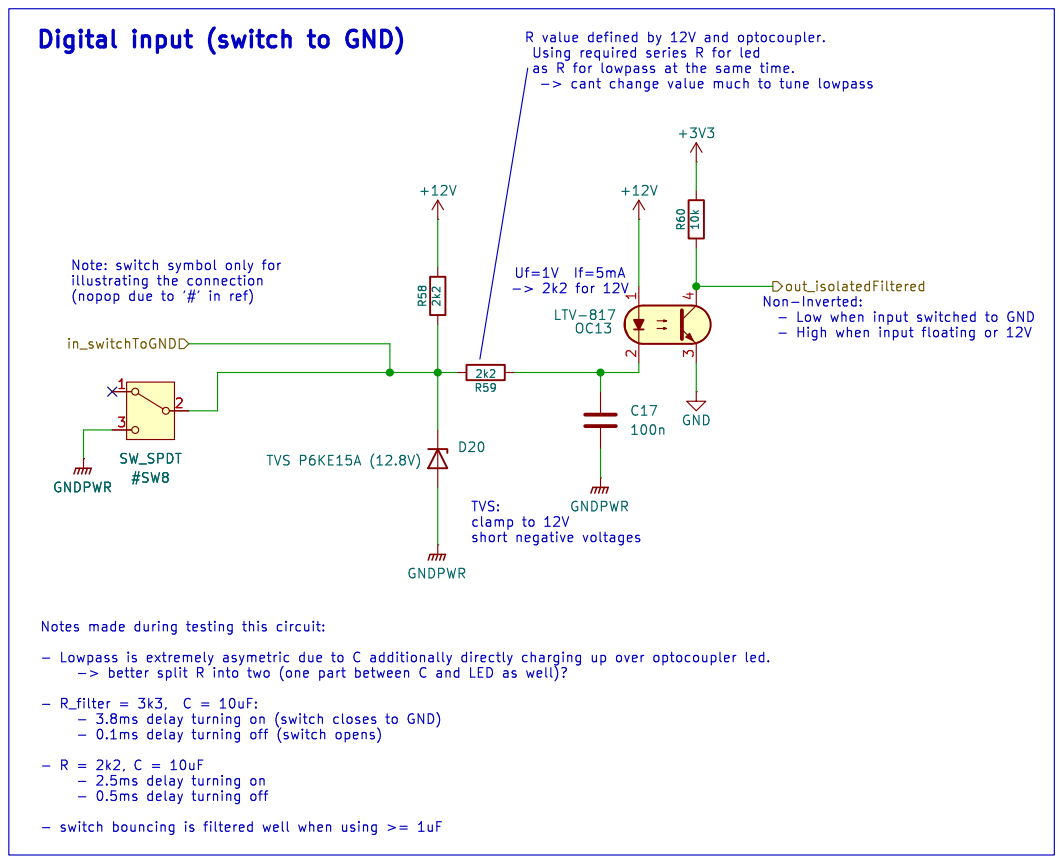
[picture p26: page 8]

Note: switch symbol only for

Id: 8/13 Title: File: isolated-digital-input_sw-to-gnd.kicad_sch Sheet: /isolated-digital-input_sw-to-gnd6/ GNDPWR GNDPWR

- 0.1ms delay turning off (switch opens)

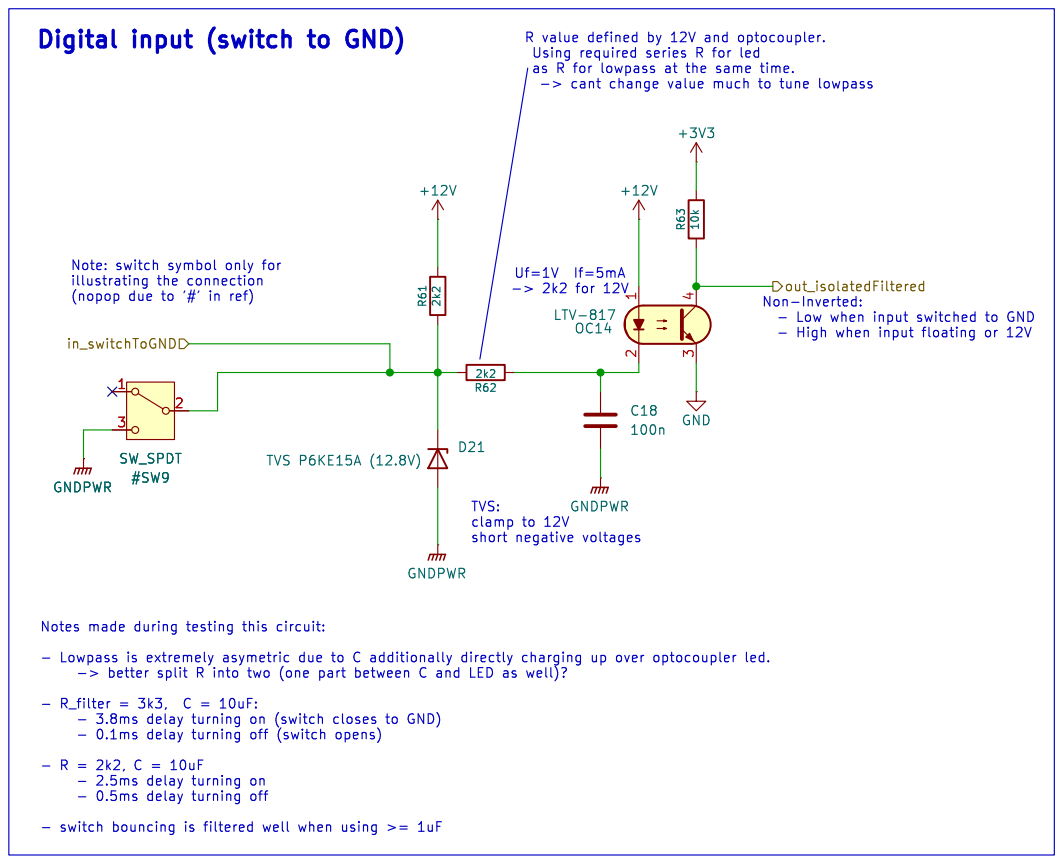
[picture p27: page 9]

Note: switch symbol only for

Id: 9/13 Title: File: isolated-digital-input_sw-to-gnd.kicad_sch Sheet: /isolated-digital-input_sw-to-gnd7/ GNDPWR GNDPWR

- 0.1ms delay turning off (switch opens)

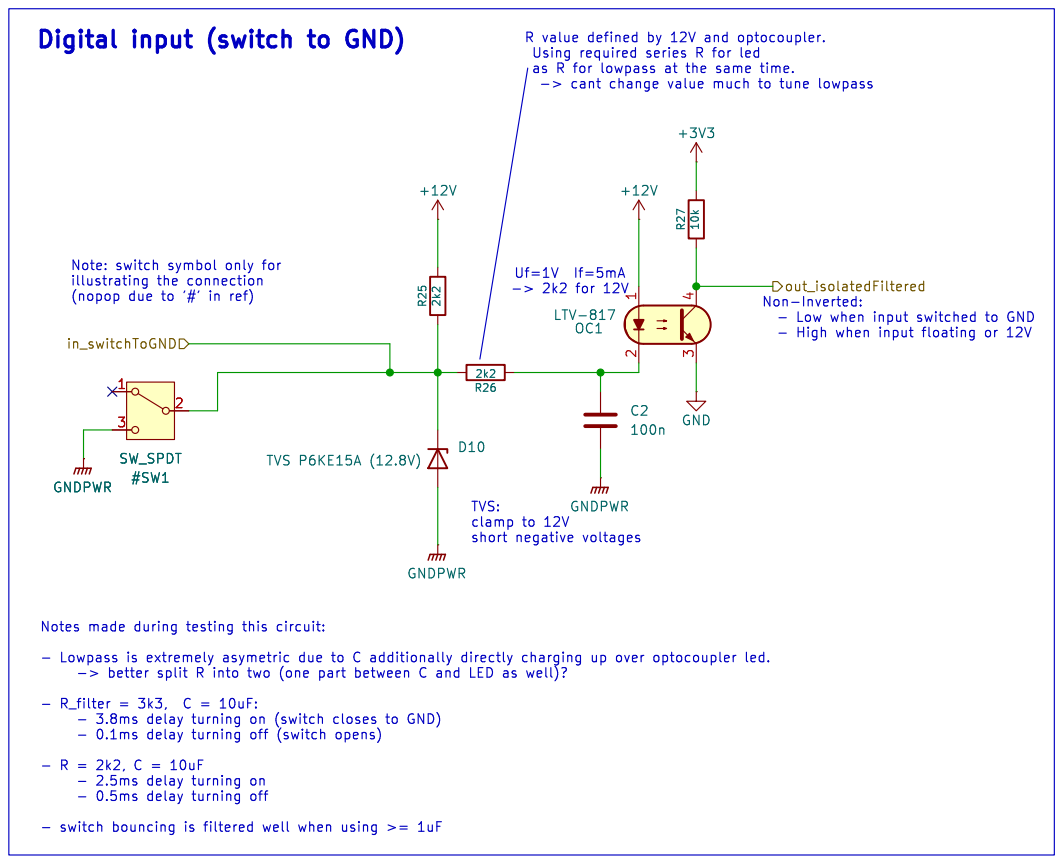
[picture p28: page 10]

Note: switch symbol only for

Id: 10/13 Title: File: isolated-digital-input_sw-to-gnd.kicad_sch Sheet: /isolated-digital-input_sw-to-gnd8/ GNDPWR GNDPWR

- 0.1ms delay turning off (switch opens)

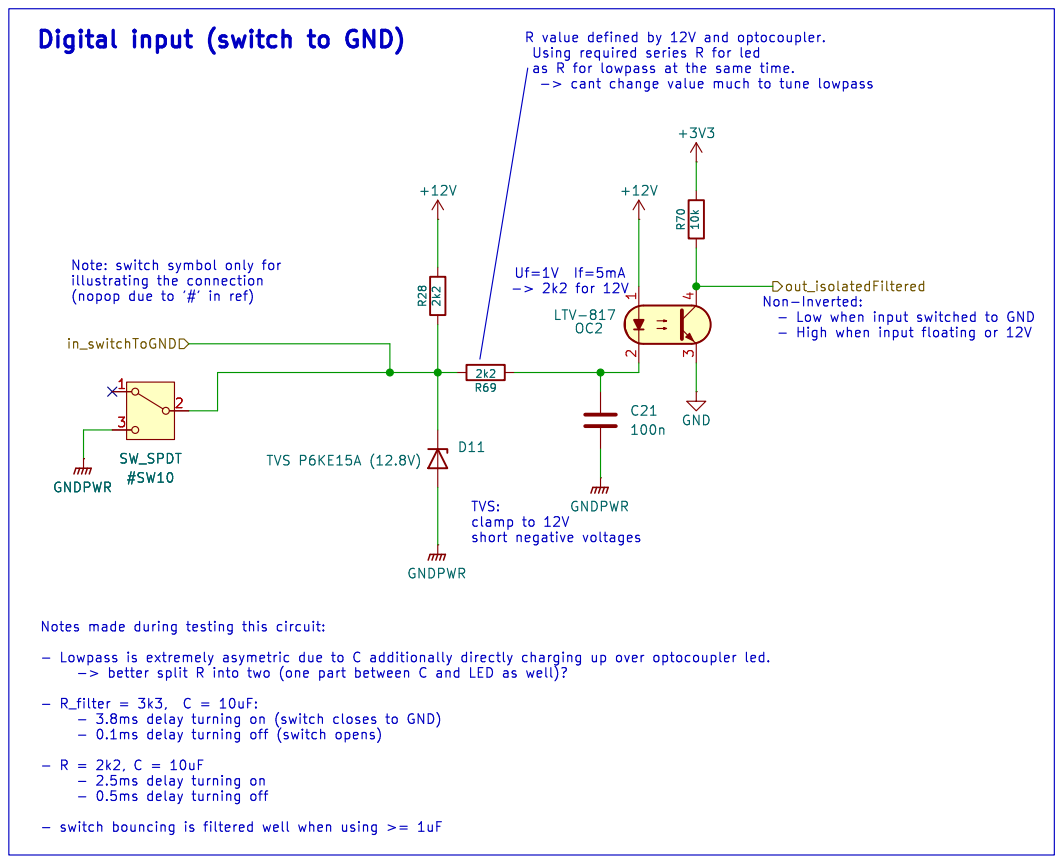
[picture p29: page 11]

Note: switch symbol only for

Id: 11/13 Title: File: isolated-digital-input_sw-to-gnd.kicad_sch Sheet: /isolated-digital-input_sw-to-gnd9/ GNDPWR GNDPWR

- 0.1ms delay turning off (switch opens)


Note: switch symbol only for

Id: 12/13 Title: File: isolated-digital-input_sw-to-gnd.kicad_sch Sheet: /isolated-digital-input_sw-to-gnd10/ GNDPWR GNDPWR

- 0.1ms delay turning off (switch opens)


Note: switch symbol only for

Id: 13/13 Title: File: isolated-digital-input_sw-to-gnd.kicad_sch Sheet: /isolated-digital-input_sw-to-gnd11/ GNDPWR GNDPWR

- 0.1ms delay turning off (switch opens)

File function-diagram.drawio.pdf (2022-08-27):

Legend; function(); command;; condition; control state: MOVING_TO_TARGET; control state: IDLE; gateLeft.close(); gateRight.close();; ButtonClose.risingEdge; gateLeft.stop(); gateRight.stop();; ButtonClose || ButtonOpen; gateLeft.open(); gateRight.open(); count++; ButtonOpen.risingEdge; buttonStart.fallingEdge && butonStart.msPressed > 1000; control state: WAIT_FOR_INPUT; count++ timestampLastAction=now(); buttonStart.risingEdge; count; timeLastAction > 1s; Open completely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

control function (interprets switches and initiates/stops gate movement)

Immediately start opening
at first start button event

Wait and analyse further input
events to decide what the user

gateLeft.setDuration(count*3)
gateRight.setDuration(count*3)

Open slightly
or more when pressed
multiple times

Receive commands again
when both gates stopped

gateLeft.state == IDLE

Stop movement when any
button is pressed during
movement to target

gateRight.state == IDLE

if-else / switch-case

STATE
of statemachine
(gets repeatedly run)

msStopTime; gate state: WAIT_LOCK; LimitSwitchClosed == false; LimitSwitchOpen || msTimeout; gate state: OPEN_START; LimitSwitchOpen; gate state: CLOSE_MOVING; close (fMsRun=msTimeout); open (fMsRun=msTimeout); relayClose.off() relayOpen.on() timestampStart = now msRun = fMsRun lastDirection = OPEN; state == IDLE; relayOpen.off() relayClose.on() timestampStart = now msRun = fMsRun lastDirection = CLOSE; stop(stopReason); [other reason]; stopReason = RETRY; msRun || LimitSwitchOpen || msTimeout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

gate class (controls the relays)

TODO: Possibility to switch
direction while moving
OPENING->CLOSING
(add delay for motors to stop)

restart when motor
started in wrong direction
when ending up at the
wrong limit switch (again)
this must be the case

//Statemachine
[switch-case with all
gate states]

relayOpen.off()
relayClose.off()
timestampStop = now
[log output + beep
depending on reason]

wait for gates to
stop moving.
locks triggering
other movement
during that time,
possibly resulting in
wront motor direction

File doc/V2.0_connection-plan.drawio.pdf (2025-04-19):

# Connection-Plan Automated Sliding Gate

VFD-BOX RS485 A; Gate 2 (East) open NO: sw closed when gate open; GND; Supply VFD-1; Supply VFD-2; VFD-BOX RS485 B; 12V supply; GND supply; Open; Close; Light Barrier lower; hin; ate-E; ast must N; e fully; close; PIO-2 / C

Open buttons
Cabinet and Gate
parallel

Close buttons

Gate 1 (West)
closed
NC: sw open
when gate

open
NO: sw closed

Gate 2 (East)

Pulls to GND
when
obstructed

Remote Control
Module
Relays removed,
Mosfets pull to
GND

## VFD-Box

### Motor

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

Wiring-Plan Automated Sliding Gate

VFD -> Motor

Oelflex 5x1mm2 - 1: U - 2: V

Gate-East, Limit-Switch-closed

Control-Box -> VFD-Box
Oelflex 5x1mm2
- gn: GND
- 1: 12V (12V power supply out)
- 4: [unused]

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

Gate-East, Limit-Switch-open
Oelflex 5x1mm2 - gn: [unused] - 1, 2: NC - 3, 4: NO

Buttons in Gate
Open/Close

Control-Box -> Servo-Motor

- gn: GND - 1: 12V supply Servo

- 2: PWM Signal

Control-Box -> light-barrier

- brown: 12V
- blue: GND
- black: collector
(pulls low when obstructed)

For flashing the
ESP32:
Gate-East must NOT
be fully closed
(GPIO-2 / C2 low)

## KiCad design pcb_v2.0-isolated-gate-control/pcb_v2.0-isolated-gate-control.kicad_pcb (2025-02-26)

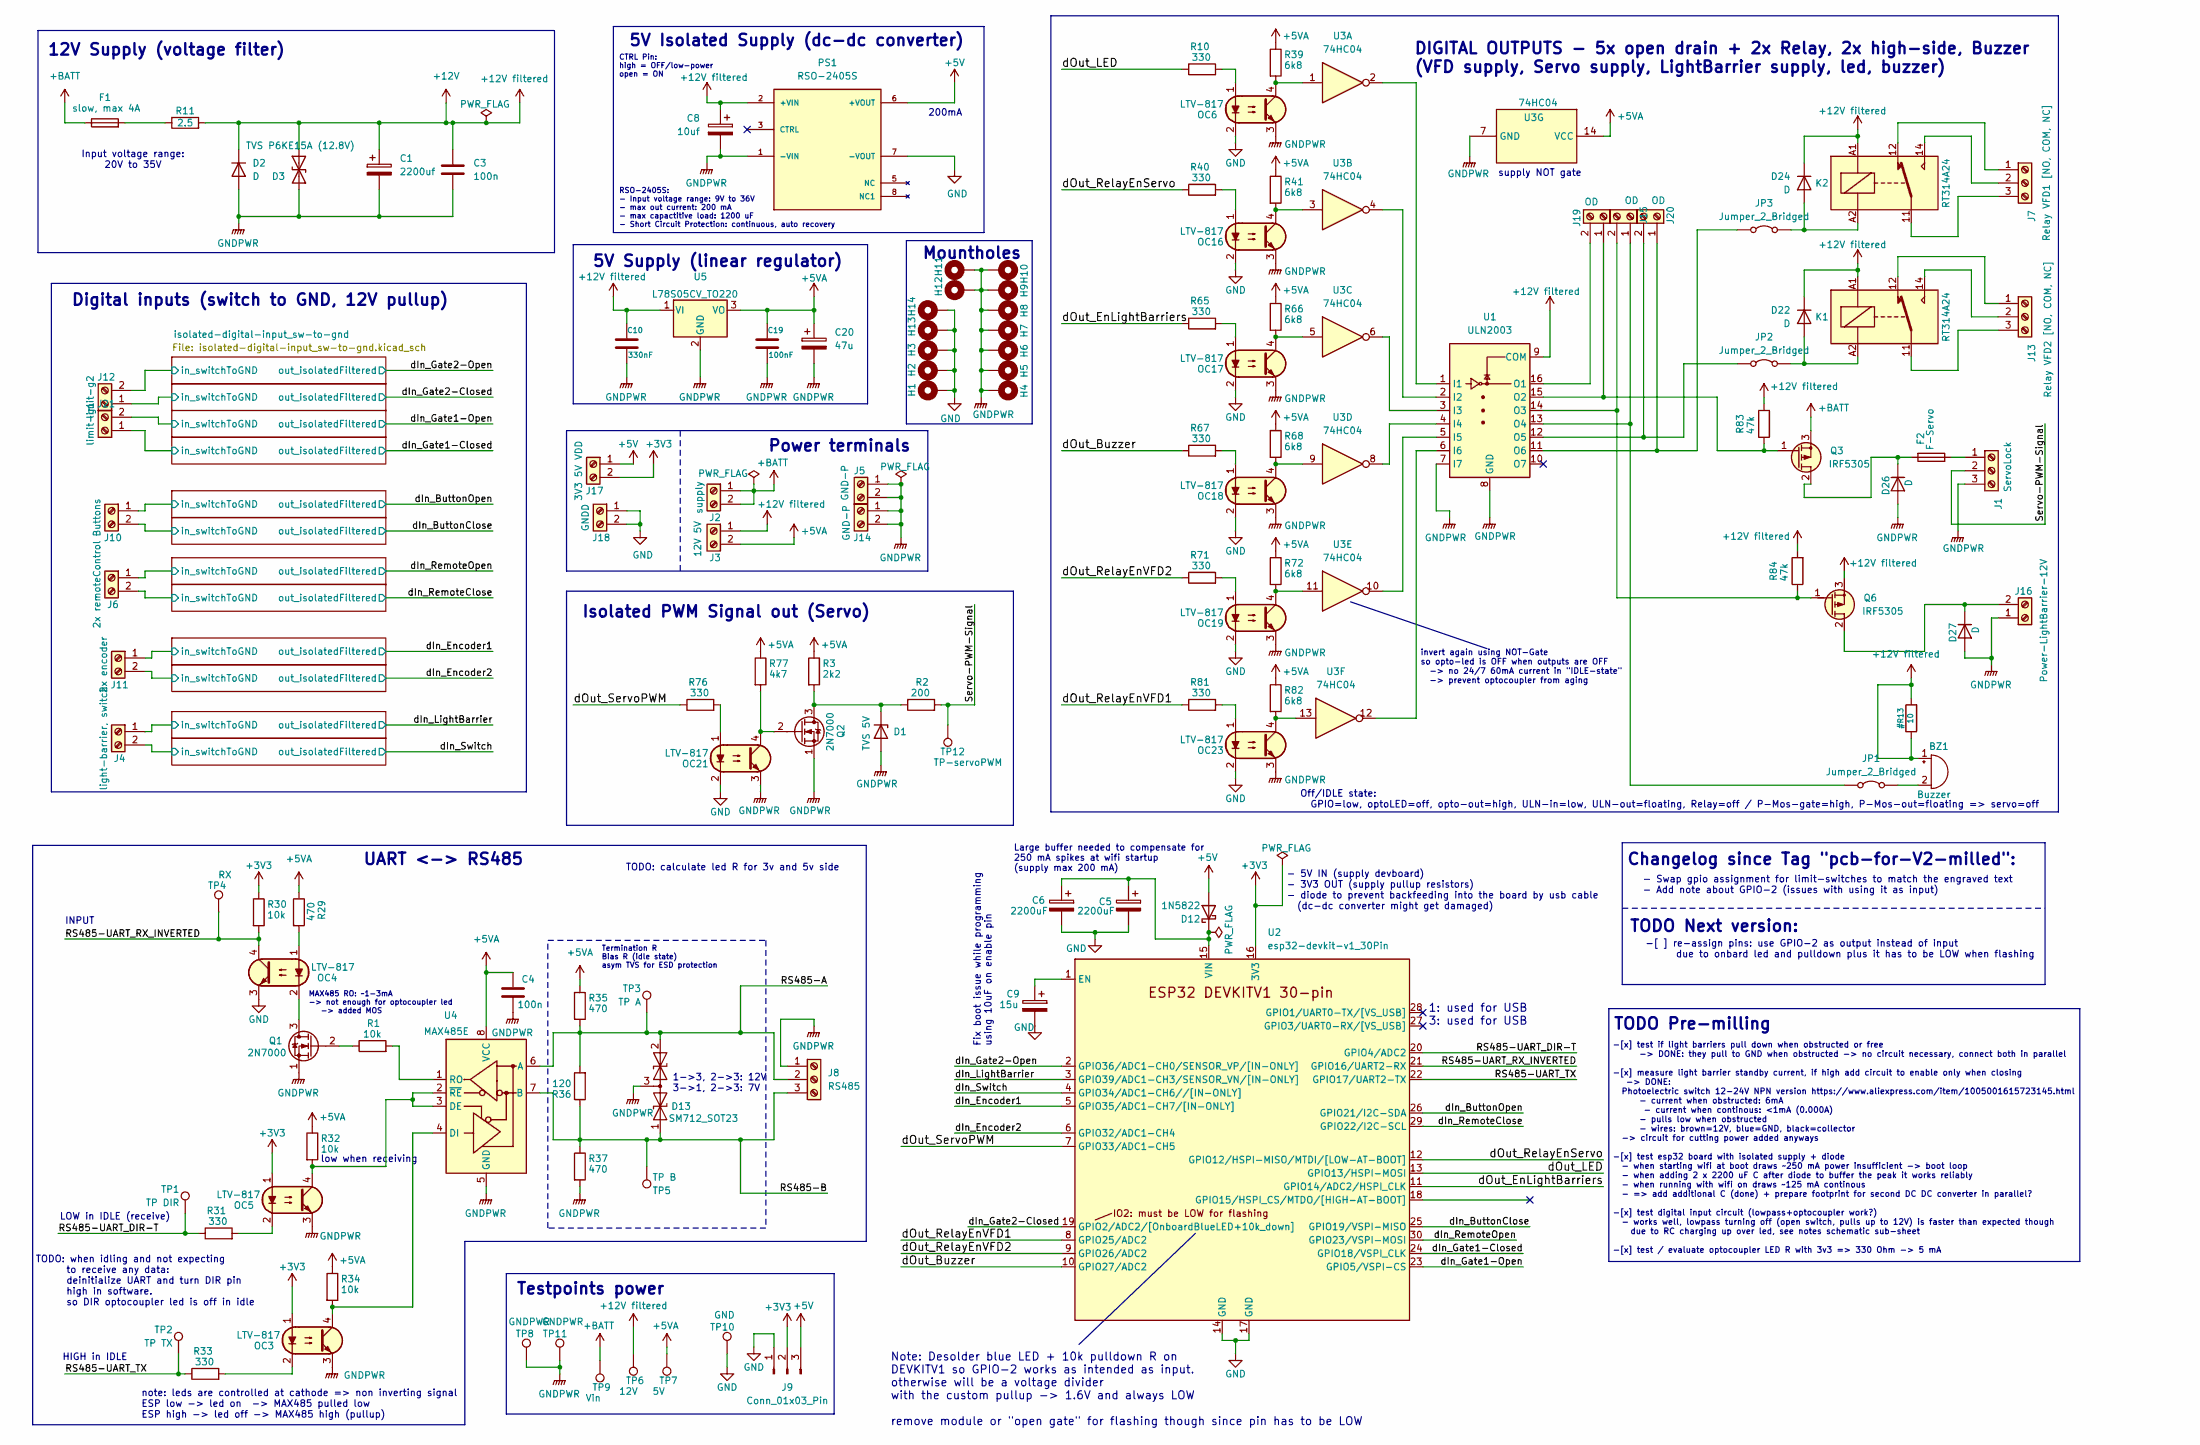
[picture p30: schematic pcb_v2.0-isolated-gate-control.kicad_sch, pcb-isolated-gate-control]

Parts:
BZ1: Buzzer; Buzzer_TDK_PS1240P02BT_D12.2mm_H6.5mm
C1: 2200uf; CP_Radial_D10.0mm_P3.80mm
C3, C4: 100n; C_Disc_D7.0mm_W2.5mm_P5.00mm
C5, C6: 2200uF; CP_Radial_D10.0mm_P5.00mm
C8: 10uf; CP_Radial_D5.0mm_P2.50mm
C9: 15u; CP_Radial_D6.3mm_P2.50mm
C10: 330nF; C_Disc_D8.0mm_W5.0mm_P5.00mm
C19: 100nF; C_Disc_D7.0mm_W2.5mm_P5.00mm
C20: 47u; CP_Radial_D5.0mm_P2.50mm
D1: TVS 5V; D_5W_P5.08mm_Vertical_AnodeUp
D2, D22, D24: D; D_T-1_P12.70mm_Horizontal
D3: TVS P6KE15A (12.8V); D_DO-201AE_P15.24mm_Horizontal
D12: 1N5822; D_DO-201AD_P15.24mm_Horizontal
D13: SM712_SOT23; SOT-23
D26, D27: D; D_DO-201_P5.08mm_Vertical_KathodeUp
F1: slow, max 4A; Fuseholder_Automotive-Mini_Fuse11x4x16_Footprint15x5_Inline
F2: F-Servo; Fuseholder_Automotive-Mini_Fuse11x4x16_Footprint15x5_Inline
H1, H2, H3, H4, H5, H6, H7, H8, H9, H10, H11, H12, H13, H14: MountingHole_Pad; MountingHole_2.2mm_NPTH-with-pad_DRC-clearance-error
J1: ServoLock; ScrewTerminal_P5mm_3Pin_FP15x8
J2: supply; ScrewTerminal_P5mm_2Pin_FP10x8
J3: 12V 5V; ScrewTerminal_P5mm_2Pin_FP10x8
J4: light-barrier, switch; ScrewTerminal_P5mm_2Pin_FP10x8
J5, J14: GND-P; ScrewTerminal_P5mm_2Pin_FP10x8
J6: 2x remoteControl; ScrewTerminal_P5mm_2Pin_FP10x8
J7: Relay VFD1 [NO, COM, NC]; ScrewTerminal_P5mm_3Pin_FP15x8
J8: RS485; ScrewTerminal_P5mm_3Pin_FP15x8
J9: Conn_01x03_Pin; PinHeader_1x03_P2.54mm_Vertical
J10: Buttons; ScrewTerminal_P5mm_2Pin_FP10x8
J11: 2x encoder; ScrewTerminal_P5mm_2Pin_FP10x8
J12: limit-g2; ScrewTerminal_P5mm_2Pin_FP10x8
J13: Relay VFD2 [NO, COM, NC]; ScrewTerminal_P5mm_3Pin_FP15x8
J15, J19, J20: OD; ScrewTerminal_P5mm_2Pin_FP10x8
J16: Power-LightBarrier-12V; ScrewTerminal_P5mm_2Pin_FP10x8
J17: 3V3 5V VDD; ScrewTerminal_P5mm_2Pin_FP10x8
J18: GNDD; ScrewTerminal_P5mm_2Pin_FP10x8
J21: limit-g1; ScrewTerminal_P5mm_2Pin_FP10x8
JP1, JP2, JP3: Jumper_2_Bridged; Jumper_P2.54mm_D0.7mm
K1, K2: RT314A24; Relay_SPDT_Schrack-RT1-16A-FormC_RM5mm
OC3, OC4, OC5, OC6, OC16, OC17, OC18, OC19, OC21, OC23: LTV-817; DIP-4_W10.16mm_LongPads
PS1: RSO-2405S; CONV_RSO-2405S; PARTREV 3
Q1, Q2: 2N7000; TO-92_HandSolder
Q3, Q6: IRF5305; TO-220-3_Vertical
R1, R30, R32, R34: 10k; R_Axial_DIN0207_L6.3mm_D2.5mm_P2.54mm_Vertical
R2: 200; R_Axial_DIN0207_L6.3mm_D2.5mm_P2.54mm_Vertical
R3: 2k2; R_Axial_DIN0207_L6.3mm_D2.5mm_P2.54mm_Vertical
R10, R31, R33, R40, R65, R67, R71, R76, R81: 330; R_Axial_DIN0207_L6.3mm_D2.5mm_P2.54mm_Vertical
R11: 2.5; Cement-Power-R_L22_W10_P23_Horizontal
R29, R35, R37: 470; R_Axial_DIN0207_L6.3mm_D2.5mm_P10.16mm_Horizontal
R36: 120; R_Axial_DIN0207_L6.3mm_D2.5mm_P2.54mm_Vertical
R39, R41, R66, R68, R72, R82: 6k8; R_Axial_DIN0207_L6.3mm_D2.5mm_P2.54mm_Vertical
R77: 4k7; R_Axial_DIN0207_L6.3mm_D2.5mm_P10.16mm_Horizontal
R83: 47k; R_Axial_DIN0207_L6.3mm_D2.5mm_P10.16mm_Horizontal
R84: 47k; R_Axial_DIN0207_L6.3mm_D2.5mm_P2.54mm_Vertical
TP1: TP DIR; PinHeader_1x01_P2.54mm_Vertical
TP2: TP TX; PinHeader_1x01_P2.54mm_Vertical
TP3: TP A; PinHeader_1x01_P2.54mm_Vertical
TP4: RX; PinHeader_1x01_P2.54mm_Vertical
TP5: TP B; PinHeader_1x01_P2.54mm_Vertical
TP6: 12V; PinHeader_1x01_P2.54mm_Vertical
TP7: 5V; PinHeader_1x01_P2.54mm_Vertical
TP8, TP11: GNDPWR; PinHeader_1x01_P2.54mm_Vertical
TP9: Vin; PinHeader_1x01_P2.54mm_Vertical
TP10: GND; PinHeader_1x01_P2.54mm_Vertical
TP12: TP-servoPWM; PinHeader_1x01_P2.54mm_Vertical
U1: ULN2003; DIP-16_W7.62mm_LongPads
U2: esp32-devkit-v1_30Pin
U3: 74HC04; DIP-14_W7.62mm_LongPads
U4: MAX485E; DIP-8_W7.62mm_LongPads
U5: L78S05CV_TO220; TO-220-3_Vertical

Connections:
+3V3: J9.2, J17.2, OC3.1, OC5.1, R30.1, U2.16 (3V3); also elsewhere on the board
+5V: D12.2 (A), J9.3, J17.1, PS1.6 (+VOUT)
+5VA: C4.1, C19.1, C20.1, J3.2, R3.1, R29.1, R32.1, R34.1, R35.1, R39.1, R41.1, R66.1, R68.1, R72.1, R77.1, R82.1, TP7.1, U3.14 (VCC), U4.8 (VCC), U5.3 (VO)
+12V: BZ1.1 (+), C1.1, C3.1, C8.1, C10.1, D2.1 (K), D3.1 (A1), D22.1 (K), D24.1 (K), J3.1, K1.A1, K2.A1, PS1.2 (+VIN), Q6.3 (S), R11.2, R83.2, R84.2, TP6.1, U1.9 (COM), U5.1 (VI); also elsewhere on the board
+BATT: F1.1, J2.1, J2.2, Q3.3 (S), TP9.1
/RS485-A: D13.2 (A2), J8.2, R35.2, R36.2, TP3.1, U4.6 (A)
/RS485-B: D13.1 (A1), J8.3, R36.1, R37.1, TP5.1, U4.7 (B)
/RS485-UART_DIR-T: R31.1, TP1.1, U2.20 (GPIO4/ADC2)
/RS485-UART_RX_INVERTED: OC4.4, R30.2, TP4.1, U2.21 (GPIO16/UART2-RX)
/RS485-UART_TX: R33.1, TP2.1, U2.22 (GPIO17/UART2-TX)
/Servo-PWM-Signal: J1.2, R2.2, TP12.1
/dIn_ButtonClose: U2.25 (GPIO19/VSPI-MISO); also elsewhere on the board
/dIn_ButtonOpen: U2.26 (GPIO21/I2C-SDA); also elsewhere on the board
/dIn_Encoder1: U2.5 (GPIO35/ADC1-CH7/[IN-ONLY]); also elsewhere on the board
/dIn_Encoder2: U2.6 (GPIO32/ADC1-CH4); also elsewhere on the board
/dIn_Gate1-Closed: U2.24 (GPIO18/VSPI_CLK); also elsewhere on the board
/dIn_Gate1-Open: U2.23 (GPIO5/VSPI-CS); also elsewhere on the board
/dIn_Gate2-Closed: U2.19 (GPIO2/ADC2); also elsewhere on the board
/dIn_Gate2-Open: U2.2 (GPIO36/ADC1-CH0/SENSOR_VP/[IN-ONLY]); also elsewhere on the board
/dIn_LightBarrier: U2.3 (GPIO39/ADC1-CH3/SENSOR_VN/[IN-ONLY]); also elsewhere on the board
/dIn_RemoteClose: U2.29 (GPIO22/I2C-SCL); also elsewhere on the board
/dIn_RemoteOpen: U2.30 (GPIO23/VSPI-MOSI); also elsewhere on the board
/dIn_Switch: U2.4 (GPIO34/ADC1-CH6//[IN-ONLY]); also elsewhere on the board
/dOut_Buzzer: R67.1, U2.10 (GPIO27/ADC2)
/dOut_EnLightBarriers: R65.1, U2.11 (GPIO14/ADC2/HSPI_CLK)
/dOut_LED: R10.1, U2.13 (GPIO13/HSPI-MOSI)
/dOut_RelayEnServo: R40.1, U2.12 (GPIO12/HSPI-MISO/MTDI/[LOW-AT-BOOT])
/dOut_RelayEnVFD1: R81.1, U2.8 (GPIO25/ADC2)
/dOut_RelayEnVFD2: R71.1, U2.9 (GPIO26/ADC2)
/dOut_ServoPWM: R76.1, U2.7 (GPIO33/ADC1-CH5)
/isolated-digital-input_sw-to-gnd1/in_switchToGND: J12.1; also elsewhere on the board
/isolated-digital-input_sw-to-gnd2/in_switchToGND: J21.2; also elsewhere on the board
/isolated-digital-input_sw-to-gnd3/in_switchToGND: J21.1; also elsewhere on the board
/isolated-digital-input_sw-to-gnd4/in_switchToGND: J10.1; also elsewhere on the board
/isolated-digital-input_sw-to-gnd5/in_switchToGND: J10.2; also elsewhere on the board
/isolated-digital-input_sw-to-gnd6/in_switchToGND: J11.1; also elsewhere on the board
/isolated-digital-input_sw-to-gnd7/in_switchToGND: J11.2; also elsewhere on the board
/isolated-digital-input_sw-to-gnd8/in_switchToGND: J6.1; also elsewhere on the board
/isolated-digital-input_sw-to-gnd9/in_switchToGND: J6.2; also elsewhere on the board
/isolated-digital-input_sw-to-gnd10/in_switchToGND: J4.1; also elsewhere on the board
/isolated-digital-input_sw-to-gnd/in_switchToGND: J12.2; also elsewhere on the board
GND: C5.2, C6.2, C9.2, H1.1, H2.1, H3.1, H13.1, H14.1, J9.1, J18.1, J18.2, OC4.3, OC6.2, OC16.2, OC17.2, OC18.2, OC19.2, OC21.2, OC23.2, PS1.7 (-VOUT), TP10.1, U2.14 (GND), U2.17 (GND); also elsewhere on the board
unnamed: BZ1.2 (-), JP1.2 (B)
unnamed: D1.1 (K), Q2.3 (D), R2.1, R3.2
unnamed: C5.1, C6.1, D12.1 (K), U2.15 (VIN)
unnamed: D22.2 (A), JP2.2 (B), K1.A2
unnamed: D24.2 (A), JP3.2 (B), K2.A2
unnamed: D26.1 (K), F2.2, Q3.2 (D)
unnamed: D27.1 (K), J16.2, Q6.2 (D)
unnamed: F1.2, R11.1
unnamed: F2.1, J1.1
unnamed: J7.1, K2.12
unnamed: J7.2, K2.14
unnamed: J7.3, K2.11
unnamed: J13.1, K1.12
unnamed: J13.2, K1.14
unnamed: J13.3, K1.11
unnamed: J15.1, JP1.1 (A), U1.13 (O4)
unnamed: J15.2, Q6.1 (G), R84.1, U1.14 (O3)
unnamed: J19.1, Q3.1 (G), R83.1, U1.15 (O2)
unnamed: J19.2, U1.16 (O1)
unnamed: J20.1, JP3.1 (A), U1.11 (O6)
unnamed: J20.2, JP2.1 (A), U1.12 (O5)
unnamed: OC3.2, R33.2
unnamed: OC4.1, R29.2
unnamed: OC5.2, R31.2
unnamed: OC6.1, R10.2
unnamed: OC6.4, R39.2, U3.1
unnamed: OC16.1, R40.2
unnamed: OC16.4, R41.2, U3.3
unnamed: OC17.1, R65.2
unnamed: OC17.4, R66.2, U3.5
unnamed: OC18.1, R67.2
unnamed: OC18.4, R68.2, U3.9
unnamed: OC19.1, R71.2
unnamed: OC19.4, R72.2, U3.11
unnamed: OC21.1, R76.2
unnamed: OC23.1, R81.2
unnamed: OC23.4, R82.2, U3.13
unnamed: OC4.2, Q1.3 (D)
unnamed: Q1.2 (G), R1.1
unnamed: OC21.4, Q2.2 (G), R77.2
unnamed: U1.1 (I1), U3.2
unnamed: U1.2 (I2), U3.4
unnamed: U1.3 (I3), U3.6
unnamed: U1.4 (I4), U3.8
unnamed: U1.5 (I5), U3.10
unnamed: U1.6 (I6), U3.12
unnamed: C9.1, U2.1 (EN)
unnamed: OC5.4, R32.2, U4.2 (~RE), U4.3 (DE)
unnamed: OC3.4, R34.2, U4.4 (DI)
unnamed: R1.2, U4.1 (RO)

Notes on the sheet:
INPUT
note: leds are controlled at cathode => non inverting signal ESP low -> led on -> MAX485 pulled low ESP high -> led off -> MAX485 high (pullup)
invert again using NOT-Gate so opto-led is OFF when outputs are OFF -> no 24/7 60mA current in "IDLE-state" -> prevent optocoupler from aging
- Swap gpio assignment for limit-switches to match the engraved text - Add note about GPIO-2 (issues with using it as input)
Isolated PWM Signal out (Servo)
LOW in IDLE (receive)
-[x] test if light barriers pull down when obstructed or free -> DONE: they pull to GND when obstructed -> no circuit necessary, connect both in parallel -[x] measure light barrier standby current, if high add circuit to enable only when closing -> DONE: Photoelectric switch 12-24V NPN version http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
Off/IDLE state: GPIO=low, optoLED=off, opto-out=high, ULN-in=low, ULN-out=floating, Relay=off / P-Mos-gate=high, P-Mos-out=floating => servo=off
5V Supply (linear regulator)
Testpoints power
12V Supply (voltage filter)
Large buffer needed to compensate for 250 mA spikes at wifi startup (supply max 200 mA)
1: used for USB 3: used for USB
5V Isolated Supply (dc-dc converter)
UART <-> RS485
TODO Next version:
MAX485 RO: ~1-3mA -> not enough for optocoupler led -> added MOS
1->3, 2->3: 12V 3->1, 2->3: 7V
supply NOT gate
TODO: when idling and not expecting to receive any data: deinitialize UART and turn DIR pin high in software. so DIR optocoupler led is off in idle
DIGITAL OUTPUTS - 5x open drain + 2x Relay, 2x high-side, Buzzer (VFD supply, Servo supply, LightBarrier supply, led, buzzer)
Power terminals
-[ ] re-assign pins: use GPIO-2 as output instead of input due to onbard led and pulldown plus it has to be LOW when flashing
- 5V IN (supply devboard) - 3V3 OUT (supply pullup resistors) - diode to prevent backfeeding into the board by usb cable (dc-dc converter might get damaged)
Input voltage range: 20V to 35V
Mountholes
Digital inputs (switch to GND, 12V pullup)
Changelog since Tag "pcb-for-V2-milled":
CTRL Pin: high = OFF/low-power open = ON
Fix boot issue while programming using 10uF on enable pin
200mA
Termination R Bias R (idle state) asym TVS for ESD protection
low when receiving
TODO Pre-milling
Note: Desolder blue LED + 10k pulldown R on DEVKITV1 so GPIO-2 works as intended as input. otherwise will be a voltage divider with the custom pullup -> 1.6V and always LOW remove module or "open gate" for flashing though since pin has to be LOW
HIGH in IDLE
RSO-2405S: - Input voltage range: 9V to 36V - max out current: 200 mA - max capactitive load: 1200 uF - Short Circuit Protection: continuous, auto recovery
TODO: calculate led R for 3v and 5v side

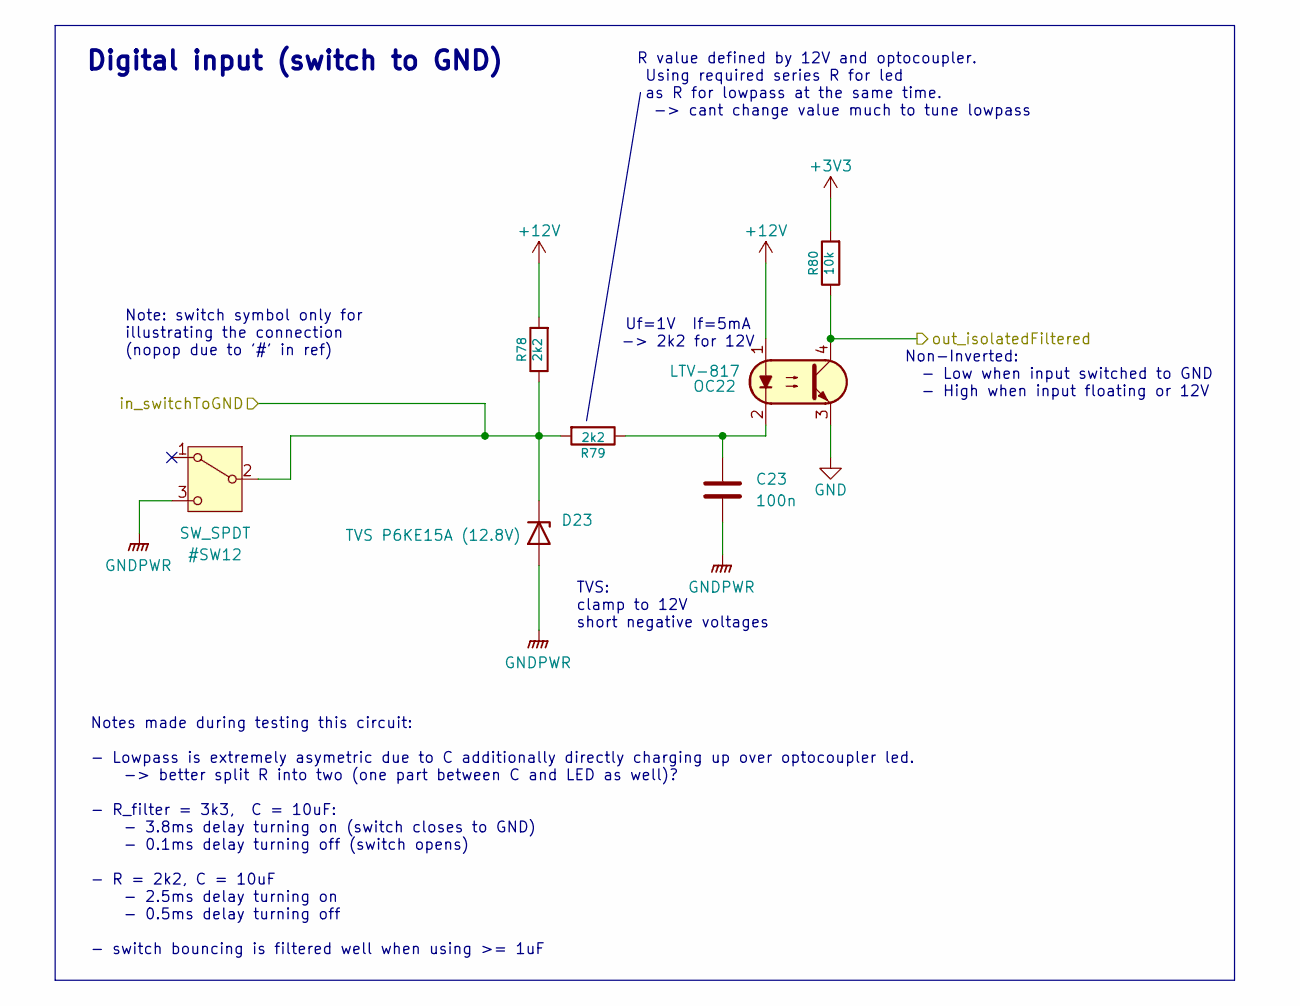
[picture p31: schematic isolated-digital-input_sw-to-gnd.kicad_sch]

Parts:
C23: 100n; C_DualType__Disc-7.0x2.5mm-P5mm__Elko-D5mm-P2.5mm
D23: TVS P6KE15A (12.8V); D_DO-41_SOD81_P12.70mm_Horizontal
OC22: LTV-817; DIP-4_W10.16mm_LongPads
R78, R79: 2k2; R_Axial_DIN0207_L6.3mm_D2.5mm_P10.16mm_Horizontal
R80: 10k; R_Axial_DIN0207_L6.3mm_D2.5mm_P2.54mm_Vertical

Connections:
+3V3: R80.2; also elsewhere on the board
+12V: OC22.1, R78.2; also elsewhere on the board
/dIn_Switch: OC22.4, R80.1; also elsewhere on the board
GND: OC22.3; also elsewhere on the board
unnamed: C23.1, OC22.2, R79.1

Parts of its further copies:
C2, C11, C12, C13, C14, C15, C16, C17, C18, C21, C22: 100n; C_DualType__Disc-7.0x2.5mm-P5mm__Elko-D5mm-P2.5mm
D5, D10, D11, D14, D15, D16, D17, D18, D19, D20, D21: TVS P6KE15A (12.8V); D_DO-41_SOD81_P12.70mm_Horizontal
OC1, OC2, OC7, OC8, OC9, OC10, OC11, OC12, OC13, OC14, OC20: LTV-817; DIP-4_W10.16mm_LongPads
R12, R25, R26, R28, R38, R43, R44, R46, R47, R49, R50, R52, R53, R55, R56, R58, R59, R61, R62, R69, R73, R74: 2k2; R_Axial_DIN0207_L6.3mm_D2.5mm_P10.16mm_Horizontal
R27, R42, R45, R48, R51, R54, R57, R60, R63, R70, R75: 10k; R_Axial_DIN0207_L6.3mm_D2.5mm_P2.54mm_Vertical

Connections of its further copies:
+3V3: R27.2, R42.2, R45.2, R48.2, R51.2, R54.2, R57.2, R60.2, R63.2, R70.2, R75.2; also elsewhere on the board
+12V: OC1.1, OC2.1, OC7.1, OC8.1, OC9.1, OC10.1, OC11.1, OC12.1, OC13.1, OC14.1, OC20.1, R12.2, R25.2, R28.2, R43.2, R46.2, R49.2, R52.2, R55.2, R58.2, R61.2, R73.2; also elsewhere on the board
/dIn_ButtonClose: OC12.4, R57.1; also elsewhere on the board
/dIn_ButtonOpen: OC11.4, R54.1; also elsewhere on the board
/dIn_Encoder1: OC13.4, R60.1; also elsewhere on the board
/dIn_Encoder2: OC14.4, R63.1; also elsewhere on the board
/dIn_Gate1-Closed: OC10.4, R51.1; also elsewhere on the board
/dIn_Gate1-Open: OC9.4, R48.1; also elsewhere on the board
/dIn_Gate2-Closed: OC8.4, R45.1; also elsewhere on the board
/dIn_Gate2-Open: OC7.4, R42.1; also elsewhere on the board
/dIn_LightBarrier: OC20.4, R75.1; also elsewhere on the board
/dIn_RemoteClose: OC2.4, R70.1; also elsewhere on the board
/dIn_RemoteOpen: OC1.4, R27.1; also elsewhere on the board
/isolated-digital-input_sw-to-gnd1/in_switchToGND: D15.1 (K), R43.1, R44.2; also elsewhere on the board
/isolated-digital-input_sw-to-gnd2/in_switchToGND: D16.1 (K), R46.1, R47.2; also elsewhere on the board
/isolated-digital-input_sw-to-gnd3/in_switchToGND: D17.1 (K), R49.1, R50.2; also elsewhere on the board
/isolated-digital-input_sw-to-gnd4/in_switchToGND: D18.1 (K), R52.1, R53.2; also elsewhere on the board
/isolated-digital-input_sw-to-gnd5/in_switchToGND: D19.1 (K), R55.1, R56.2; also elsewhere on the board
/isolated-digital-input_sw-to-gnd6/in_switchToGND: D20.1 (K), R58.1, R59.2; also elsewhere on the board
/isolated-digital-input_sw-to-gnd7/in_switchToGND: D21.1 (K), R61.1, R62.2; also elsewhere on the board
/isolated-digital-input_sw-to-gnd8/in_switchToGND: D10.1 (K), R25.1, R26.2; also elsewhere on the board
/isolated-digital-input_sw-to-gnd9/in_switchToGND: D11.1 (K), R28.1, R69.2; also elsewhere on the board
/isolated-digital-input_sw-to-gnd10/in_switchToGND: D14.1 (K), R73.1, R74.2; also elsewhere on the board
/isolated-digital-input_sw-to-gnd/in_switchToGND: D5.1 (K), R12.1, R38.2; also elsewhere on the board
GND: OC1.3, OC2.3, OC7.3, OC8.3, OC9.3, OC10.3, OC11.3, OC12.3, OC13.3, OC14.3, OC20.3; also elsewhere on the board
unnamed: C2.1, OC1.2, R26.1
unnamed: C11.1, OC7.2, R38.1
unnamed: C12.1, OC8.2, R44.1
unnamed: C13.1, OC9.2, R47.1
unnamed: C14.1, OC10.2, R50.1
unnamed: C15.1, OC11.2, R53.1
unnamed: C16.1, OC12.2, R56.1
unnamed: C17.1, OC13.2, R59.1
unnamed: C18.1, OC14.2, R62.1
unnamed: C21.1, OC2.2, R69.1
unnamed: C22.1, OC20.2, R74.1

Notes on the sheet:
Note: switch symbol only for illustrating the connection (nopop due to '#' in ref)
R value defined by 12V and optocoupler. Using required series R for led as R for lowpass at the same time. -> cant change value much to tune lowpass
TVS: clamp to 12V short negative voltages
Digital input (switch to GND)
Non-Inverted: - Low when input switched to GND - High when input floating or 12V
Notes made during testing this circuit: - Lowpass is extremely asymetric due to C additionally directly charging up over optocoupler led. -> better split R into two (one part between C and LED as well)? - R_filter = 3k3, C = 10uF: - 3.8ms delay turning on (switch closes to GND) - 0.1ms delay turnin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
Uf=1V If=5mA -> 2k2 for 12V

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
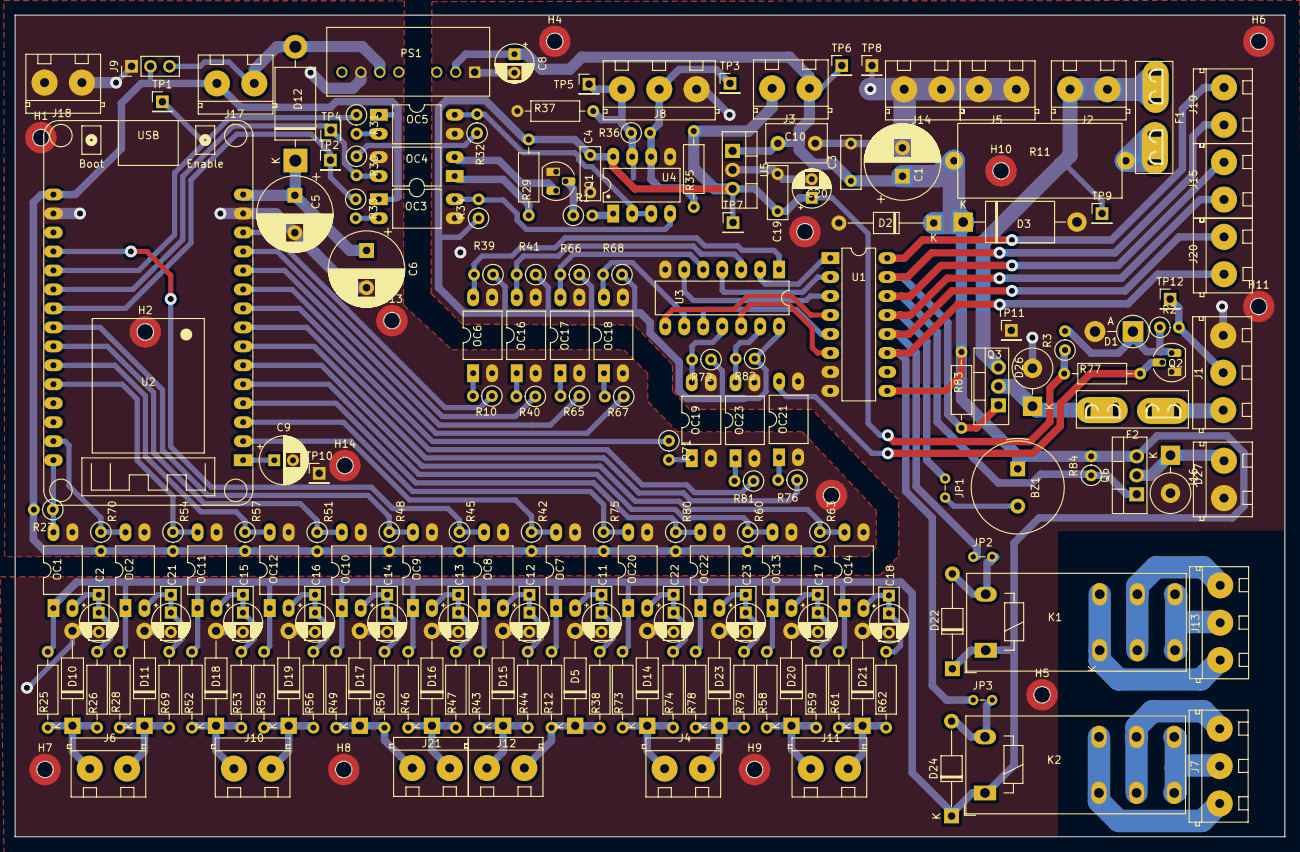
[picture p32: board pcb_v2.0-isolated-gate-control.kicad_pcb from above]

Board: 4 copper layers, 170.0 x 110.0 mm, 195 parts (1 on the bottom side), 106 nets.

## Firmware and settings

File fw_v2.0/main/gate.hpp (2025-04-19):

#pragma once
#ifndef GATE_HPP
#define GATE_HPP

#include "vfd.hpp"
#include "buzzer.hpp"
#include <driver/gpio.h>
#include <esp_log.h>
#include <string>
#include <algorithm>  // for std::clamp
#include "freertos/FreeRTOS.h"
#include "freertos/task.h"
#include "buzzer.hpp"

// Define a delay (in milliseconds) waited for the VFD startup after the relay is turned on.
#define DELAY_VFD_STARTUP 870
    // 900 worked well, but feels long...
    // 800 west gate unreliable sometimes it does not start...
    // 700 too short, west gate did not start properly
    // it seems VFD recognizes command, but needs some time to finish booting and only starts later anyways
// TODO: test individual delay for each VFD

// #define IGNORE_VFD_ERROR // if defined does not force realy off when stop command fails
#define RELAY_INACTIVITY_TIMEOUT_MS (3*60 + 0)*60*1000  // 1h too short (often off during active day) -> 3h 0min

// #define LOG_VFD_CURRENT_WHEN_CLOSING
#define CURRENT_MONITORING_ENABLED
#define DEFAULT_VFD_CURRENT_LIMIT 0.60

#define DEFAULT_VFD_FREQUENCY 50 // motor speed in Hz
#define BEEP_AT_LIMIT_SW_CHANGE

#define PAUSED_SWITCH_TO_IDLE_TIMEOUT_MS 30*1000

// Gate state strings for logging
extern const char *GateState_str [8];

// Gate state definitions.
enum GateState {
    IDLE_FULLY_OPEN = 0,
    IDLE_FULLY_CLOSED,
    IDLE_PARTIALLY_OPEN,
    WAITING_FOR_VFD_STARTUP,
    MOVING_OPENING,
    MOVING_CLOSING,
    PAUSED_STATE,
    ERROR_STATE
};

class Gate {
public:
    // Constructor.
    Gate(const char *name,
         gpio_num_t kLimitSwitchOpenGpio,
         bool kLimitSwitchOpen_ActiveLevel,
         gpio_num_t kLimitSwitchClosedGpio,
         bool kLimitSwitchClosed_ActiveLevel,
         gpio_num_t kRelayPinGpio,

         VFD *vfd,
         buzzer_t *buzzer,

         uint32_t runDurationMs
    );

    // Public movement methods.
    // runTo() moves the gate to the target percentage.
    // If target is 0 or 100, a full movement is forced by using the full timeout.
    void runTo(float targetPercent);
    void openForMs(uint32_t ms);
    void openCompletely();
    void closeForMs(uint32_t ms);
    void closeCompletely();
    void updateTargetRunTime(uint32_t ms);
    void stop(bool forceStatePartialOpen = true);
    void pause();
    void resume();
    void cancel();

    // The state machine to be called periodically.
    void handle();

    // Retrieve the current state.
    GateState getState() const {return state;};
    bool getIsIdling() const {return state == IDLE_FULLY_OPEN || state == IDLE_FULLY_CLOSED || state == IDLE_PARTIALLY_OPEN;};
    bool getIsMoving() const {return state == MOVING_CLOSING || state == MOVING_OPENING || state == WAITING_FOR_VFD_STARTUP;};
    bool getIsClosing() const {return state == MOVING_CLOSING;};


private:
    // ==== CONFIG ====
    static constexpr float kDefaultVfdFrequency = 40.0f;  // Frequency (Hz) to use when running
    static constexpr float kCurrentLimitAmpere = DEFAULT_VFD_CURRENT_LIMIT;  // Max VFD current when closing for gate to stop
    static constexpr uint32_t kRelayInactivityTimeoutMs = RELAY_INACTIVITY_TIMEOUT_MS;      // Inactivity timeout (for relay turn-off)
    static constexpr uint32_t kMovingTimeout = 15e3;  // Max allowed time for continuous opening / closing movement without reaching limit


    const char* name;             // Gate name (used as the log tag)
    const gpio_num_t kLimitSwitchOpenGpio;   // GPIO for the open limit switch
    const bool kLimitSwitchOpen_ActiveLevel; // Voltage level when switch is active (high/low)
    const gpio_num_t kLimitSwitchClosedGpio; // GPIO for the closed limit switch
    const bool kLimitSwitchClosed_ActiveLevel; // Voltage level when switch is active (high/low)
    const gpio_num_t kRelayPinGpio;          // GPIO for the VFD supply relay

    VFD* const vfd;       // Pointer to the associated VFD object
    buzzer_t* const buzzer; // Pointer to the buzzer object

    const float defaultFrequency = DEFAULT_VFD_FREQUENCY;  // Frequency (Hz) to use when running
    const uint32_t runDurationMs;  // Full run duration (0% to 100%) in milliseconds

    uint64_t timestampStartUs; // Timestamp (in microseconds) when movement started
    uint64_t targetRunTimeMs;  // Desired movement duration (in microseconds) for partial moves

    GateState state;               // Current state of the gate
    bool nextDirection;             // Store desired gate direction while waiting for vfd startup
    uint64_t lastActivityTimestampUs; // For relay timeout control
    bool relayTimeoutActive;       // Flag indicating a soft-stop request for the relay
    bool relayOn;                  // Whether the relay is currently on
    uint64_t timestampRelayTurnedOnUs;

    float positionPercent;         // Current estimated position (0% = closed, 100% = open)
    uint64_t lastPositionUpdateTimestampUs; // Timestamp of last position update

    // Variables to track previous state of limit switches (for logging changes)
    bool prevOpenSwitchState;
    bool prevClosedSwitchState;

    // Variables for pause/resume support
    bool wasOpeningBeforePause = false;
    uint64_t pauseStartTimestampUs = 0;

    // Private helper methods.
    void startRelay();
    void softStopRelay();
    void forceStopRelay();
    void updatePosition();
    bool checkLimitSwitchOpenActive();
    bool checkLimitSwitchClosedActive();
    bool checkCurrentLimitExceeded();

    // Private movement helper: start movement in the given direction.
    // 'opening' = true means start opening, false means start closing.
    void startMovement(bool opening);

};

#endif // GATE_HPP

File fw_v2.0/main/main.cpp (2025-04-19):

extern "C" {
#include <stdio.h>
#include <string.h>
#include "freertos/FreeRTOS.h"
#include "freertos/task.h"
#include "driver/uart.h"
#include "esp_log.h"
#include "driver/gpio.h"

#include "modbus.h"
#include "iotest.h"
#include "config.h"
}

#include "vfd.hpp"
#include "buzzer.hpp"
#include "gate.hpp"

#include "control.hpp"


static const char *TAG = "main";
//create buzzer object 
// configured with 0ms gap between beep events
buzzer_t buzzer(CONFIG_BUZZER_GPIO, 0);

//======================================
//============ buzzer task =============
//======================================
//TODO: move the task creation to buzzer class (buzzer.cpp)
//e.g. only have function buzzer.createTask() in app_main
void task_buzzer( void * pvParameters ){
    ESP_LOGI("task_buzzer", "Start of buzzer task...");
        //run function that waits for a beep events to arrive in the queue
        //and processes them
        buzzer.processQueue();
}

// Configure all GPIO pins according to config.h
void configure_gpio_pins() {
    // TODO: most pins are initialized in the task they are used, thus can be dropped here -> move to iotest only?
    // configuration struct for gpio pins
    gpio_config_t io_conf;

    ESP_LOGW(TAG, "configuring GPIO pins...");

    // configure all inputs at once
    uint64_t input_pins = 
        (1ULL << CONFIG_SW_G1_OPEN_GPIO) |
        (1ULL << CONFIG_SW_G1_CLOSED_GPIO) |
        (1ULL << CONFIG_SW_G2_OPEN_GPIO) |
        (1ULL << CONFIG_SW_G2_CLOSED_GPIO) |
        (1ULL << CONFIG_ENCODER1_GPIO) |
        (1ULL << CONFIG_ENCODER2_GPIO) |
        (1ULL << CONFIG_BTN_OPEN_GPIO) |
        (1ULL << CONFIG_BTN_CLOSE_GPIO) |
        (1ULL << CONFIG_REMOTE_OPEN_GPIO) |
        (1ULL << CONFIG_REMOTE_CLOSE_GPIO) |
        (1ULL << CONFIG_LIGHTBARRIER_GPIO) |
        (1ULL << CONFIG_FN_BUTTON_GPIO);
    io_conf.intr_type = GPIO_INTR_DISABLE; // Disable interrupts
    io_conf.mode = GPIO_MODE_INPUT;       // Set as input
    io_conf.pin_bit_mask = input_pins;    // Pin mask for inputs
    io_conf.pull_down_en = GPIO_PULLDOWN_DISABLE; // No internal pulldown (external pullup present)
    io_conf.pull_up_en = GPIO_PULLUP_DISABLE;     // No internal pullup (optocoupler pulls low when active)
    gpio_config(&io_conf);

    // configure all outputs at once
    uint64_t output_pins = 
        (1ULL << CONFIG_SERVO_ENABLE_GPIO) |
        (1ULL << CONFIG_LIGHTBARRIER_EN_GPIO) |
        (1ULL << CONFIG_LED_GPIO) |
        (1ULL << CONFIG_BUZZER_GPIO) |
        (1ULL << CONFIG_RELAY_VFD1_GPIO) |
        (1ULL << CONFIG_RELAY_VFD2_GPIO) |
        (1ULL << CONFIG_SERVO_PWM_GPIO) |
        (1ULL << CONFIG_RS485_DIR_GPIO) |
        (1ULL << CONFIG_RS485_TX_GPIO);
    io_conf.mode = GPIO_MODE_OUTPUT;      // Set as output
    io_conf.pin_bit_mask = output_pins;  // Pin mask for outputs
    gpio_config(&io_conf);

    ESP_LOGW(TAG, "done.");
}



// Task function that repeatedly calls gate1.handle()
void gateHandleTask(void *pvParameters)
{
    Gate* gate = (Gate*) pvParameters;
    while (true) {
        gate->handle();
        vTaskDelay(pdMS_TO_TICKS(500));  // Call handle() every 100 ms.
    }
}






//#define RUN_GPIO_TEST
//#define RUN_MODBUS_TEST
//#define RUN_GATE_TEST

extern "C" void app_main(void)
{

    // initialize gpio pins as inputs/outputs
    configure_gpio_pins();

    // Configure UART
    modbus_init();

    // set loglevel
    esp_log_level_set("Modbus-RTU", ESP_LOG_WARN);
    esp_log_level_set("IO-test", ESP_LOG_INFO);
    esp_log_level_set("VFD", ESP_LOG_INFO);
    esp_log_level_set("Gate1_West", ESP_LOG_INFO);
    esp_log_level_set("Gate2_East", ESP_LOG_INFO);
    esp_log_level_set("buzzer", ESP_LOG_ERROR);
    esp_log_level_set("control", ESP_LOG_INFO);

    //--- create task for buzzer ---
    xTaskCreate(&task_buzzer, "task_buzzer", 2048, NULL, 5, NULL);

    // beep at startup
    buzzer.beep(3, 50, 100);

    // Create VFD instances
    VFD vfd1(11); // VFD 1 with address 0x11
    VFD vfd2(77); // VFD 2 with address 0x77
    // Note: trying higher / more individual addresses to not be potentially confused with function codes



    // Create a Gate instance using the configured GPIOs.
    // Parameters:
    //   - Gate name: "Gate1"
    //   - kLimitSwitchOpenGpio: CONFIG_SW_G1_OPEN_GPIO (e.g., GPIO_NUM_5)
    //   - kLimitSwitchClosedGpio: CONFIG_SW_G1_CLOSED_GPIO (e.g., GPIO_NUM_18)
    //   - kRelayPinGpio: CONFIG_RELAY_VFD1_GPIO (e.g., GPIO_NUM_25)
    //   - pointer to VFD instance: vfd1 (created earlier)
    //   - pointer to Buzzer instance: buzzer (assumed global or instantiated)
    //   - full run duration (0% to 100%): 5000 ms
    Gate gate1West("Gate1_West",
               CONFIG_SW_G1_OPEN_GPIO, 0, // active low (switch NO to GND -> optocoupler ON)
               CONFIG_SW_G1_CLOSED_GPIO, 1, // active high (switch NC to GND -> optocoupler OFF)
               CONFIG_RELAY_VFD1_GPIO,
               &vfd1,
               &buzzer,
               9000 + 1000
    );



// at 45Hz 2 start time:
// gate1 west: 9s
// gate2 east: 11s

// open:
// west: 10s, east: 11s
// ----
// 50 Hz start setting 7:
// 9s and 10s

    Gate gate2East("Gate2_East",
               CONFIG_SW_G2_OPEN_GPIO, 0, // active low (switch NO to GND -> optocoupler ON)
               CONFIG_SW_G2_CLOSED_GPIO, 1, // active high (switch NC to GND -> optocoupler OFF)
               CONFIG_RELAY_VFD2_GPIO,
               &vfd2,
               &buzzer,
               10000 + 1000
    );



ControlConfig controlConfig = {
    .gateA = &gate1West,
    .gateB = &gate2East,
    .remoteOpenGpio = CONFIG_REMOTE_OPEN_GPIO,
    .remoteCloseGpio = CONFIG_REMOTE_CLOSE_GPIO,
    .buttonOpenGpio = CONFIG_BTN_OPEN_GPIO,
    .buttonCloseGpio = CONFIG_BTN_CLOSE_GPIO,
    .faultLedGpio = CONFIG_LED_GPIO,
    .lightBarrierGpio = CONFIG_LIGHTBARRIER_GPIO,
    .buzzer = &buzzer
};

#ifndef RUN_GATE_TEST
#ifndef RUN_MODBUS_TEST
    // Create Task handling user input and the gates
    xTaskCreate(controlTask, "ControlTask", 4096*2, (void*)&controlConfig, 5, nullptr);
#endif
#endif



#ifdef RUN_GATE_TEST
    // Create a task that continuously calls gate1.handle()
    xTaskCreate(gateHandleTask, "gateHandleTask", 2048*5, &gate1, 5, NULL);



    ESP_LOGW("GateTest", "Starting Gate Test Sequence.");

    // --- Test Sequence with simple delays ---
    
    // 1. Open the gate for 3000 ms.
    ESP_LOGW("GateTest", "Command: Open for 3000 ms");
    gate1.openForMs(3000);
    vTaskDelay(pdMS_TO_TICKS(10000));  // Wait longer than 3000 ms to let the movement finish

    // 2. Run the gate to fully open (100%).
    ESP_LOGW("GateTest", "Command: Run to 100%% (Fully Open)");
    gate1.runTo(100.0f);
    vTaskDelay(pdMS_TO_TICKS(10000));  // Wait long enough for full open movement

    // 3. Run the gate to fully close (0%).
    ESP_LOGW("GateTest", "Command: Run to 0%% (Fully Closed)");
    gate1.runTo(0.0f);
    vTaskDelay(pdMS_TO_TICKS(10000));  // Wait long enough for full close movement

    // 4. Open the gate for 5000 ms, but stop it manually after 2000 ms.
    ESP_LOGW("GateTest", "Command: Open for 5000 ms, manual stop after 2000 ms");
    gate1.openForMs(5000);
    vTaskDelay(pdMS_TO_TICKS(2000));  // Wait 2 seconds
    ESP_LOGW("GateTest", "Command: stopping gate");
    gate1.stop();                     // Issue a stop command
    vTaskDelay(pdMS_TO_TICKS(3000));  // Allow time for the stop to take effect

    ESP_LOGW("GateTest", "Gate Test Sequence Completed.");
    
    // Optionally, suspend or delete this task if no further testing is required.
    vTaskDelay(pdMS_TO_TICKS(100000));
    vTaskDelete(NULL);

#endif


#ifdef RUN_MODBUS_TEST

    gpio_set_level(CONFIG_RELAY_VFD1_GPIO, 1);
    gpio_set_level(CONFIG_RELAY_VFD2_GPIO, 1);
    ESP_LOGW(TAG, "Modbus test: turned on relay, waitin 2s for vfd startup...");
    vTaskDelay(pdMS_TO_TICKS(2000));
        vfd1.setFrequency(20); // Set frequency to 200 Hz

    while (1)
    {
        uint16_t temperature;
        float voltage, current;

        // Control VFD 1
        //ESP_LOGW(TAG, "test FORWARD operation...");
        //vfd1.setFrequency(20); // Set frequency to 200 Hz
        //vfd1.start(true);
        //vTaskDelay(pdMS_TO_TICKS(2000));
        //vfd1.getVoltage(&voltage);
        //vfd1.getCurrent(&current);
        //vfd1.getTemperature(&temperature);
        //ESP_LOGI("Main", "VFD1 -> Voltage: %.1f V, Current: %.1f A, Temperature: %d C", voltage, current, temperature);
        //vfd1.stop();
        //ESP_LOGW(TAG, "turning off for 2s");
        //vTaskDelay(pdMS_TO_TICKS(2000));

        ESP_LOGW(TAG, "test REVERSE operation...");
        vfd1.start(false);
        vTaskDelay(pdMS_TO_TICKS(2000));
        vfd1.getVoltage(&voltage);
        vfd1.getCurrent(&current);
        vfd1.getTemperature(&temperature);
        ESP_LOGI("Main", "VFD1 -> Voltage: %.1f V, Current: %.1f A, Temperature: %d C", voltage, current, temperature);
        vfd1.stop();
        ESP_LOGW(TAG, "turning off for 2s");
        vTaskDelay(pdMS_TO_TICKS(2000));

        //// Control VFD 2
        //vfd2.setFrequency(10); // Set frequency to 150 Hz
        //vfd2.start();
        //vTaskDelay(pdMS_TO_TICKS(1500));
        //vfd2.getVoltage(&voltage);
        //vfd2.getCurrent(&current);
        //vfd2.getTemperature(&temperature);
        //ESP_LOGI("Main", "VFD2 -> Voltage: %d, Current: %d, Temperature: %d", voltage, current, temperature);
        //vfd2.stop();

    }

#endif


#ifdef RUN_GPIO_TEST
    // GPIO Test
    ESP_LOGW(TAG, "starting GPIO test");
    while (1)
    {
        ioTest_readAllInputs();
        ioTest_setOutputsToInputStates();
        vTaskDelay(pdMS_TO_TICKS(300));
    }
#endif


// keep main task alive forever 
// (prevent deconstruction of objects passed to tasks)
while(1) vTaskDelay(portMAX_DELAY); 

}

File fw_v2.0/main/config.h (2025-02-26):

#pragma once
#include "driver/gpio.h"

// Assign GPIO pins and configure options in this file


//==========================================
//===== UART / RS485 / Modbus settings =====
//==========================================
#define CONFIG_BAUD_RATE            9600  //vfd supports: 4800, 9600, 19200, 38400
#define CONFIG_RS485_DIR_GPIO       GPIO_NUM_4
#define CONFIG_RS485_TX_GPIO        GPIO_NUM_17
#define CONFIG_RS485_RX_GPIO        GPIO_NUM_16
#define CONFIG_RS485_RX_INVERTED    1 // 1 if RX signal is inverted, 0 otherwise



//===========================
//===== Input GPIO pins =====
//===========================
// unless noted otherwise, all inputs are active LOW (switches wired to pull input to GND)
#define CONFIG_SW_G1_OPEN_GPIO      GPIO_NUM_5   // Limit switch for Gate 1: Open (switch closed to GND (LOW) when gate is fully open)
#define CONFIG_SW_G1_CLOSED_GPIO    GPIO_NUM_18  // Limit switch for Gate 1: Closed (switch OPEN (HIGH) when gate is fully closed)
#define CONFIG_SW_G2_OPEN_GPIO      GPIO_NUM_36  // Limit switch for Gate 2: Open (switch closed to GND (LOW) when gate is fully open)
#define CONFIG_SW_G2_CLOSED_GPIO    GPIO_NUM_2   // Limit switch for Gate 2: Closed (switch open (HIGH) when gate is fully closed)

#define CONFIG_FN_BUTTON_GPIO       GPIO_NUM_34  // Function button
#define CONFIG_ENCODER1_GPIO        GPIO_NUM_35  // Encoder Gate 1 signal
#define CONFIG_ENCODER2_GPIO        GPIO_NUM_32  // Encoder Gate 2 signal
#define CONFIG_LIGHTBARRIER_GPIO    GPIO_NUM_39  // Light barrier input (NPN sensor pulls low when obstructed)

#define CONFIG_BTN_OPEN_GPIO        GPIO_NUM_21  // Button Open
#define CONFIG_BTN_CLOSE_GPIO       GPIO_NUM_19  // Button Close
#define CONFIG_REMOTE_OPEN_GPIO     GPIO_NUM_23  // Remote Open signal
#define CONFIG_REMOTE_CLOSE_GPIO    GPIO_NUM_22  // Remote Close signal

// Logical inversion for specific signals
#define CONFIG_SW_G1_CLOSED_INVERTED 1  // Gate 1 Closed signal is inverted (switch only open when gate is fully closed)
#define CONFIG_SW_G2_CLOSED_INVERTED 1  // Gate 2 Closed signal is inverted (switch only open when gate is fully closed)



//============================
//===== Output GPIO pins =====
//============================
#define CONFIG_SERVO_ENABLE_GPIO    GPIO_NUM_12  // P-MOSFET Enable supply for Servo (outputs 12V when HIGH)
#define CONFIG_LIGHTBARRIER_EN_GPIO GPIO_NUM_14  // P-MOSFET Enable supply for Light Barrier (outputs 12V-filtered when HIGH)
#define CONFIG_LED_GPIO             GPIO_NUM_13  // Status LED (outputs GND when HIGH)
#define CONFIG_BUZZER_GPIO          GPIO_NUM_27  // Buzzer (on when HIGH)
#define CONFIG_RELAY_VFD1_GPIO      GPIO_NUM_25  // Relay for VFD1 (turns Relay on when HIGH)
#define CONFIG_RELAY_VFD2_GPIO      GPIO_NUM_26  // Relay for VFD2 (turns Relay on when HIGH)
#define CONFIG_SERVO_PWM_GPIO       GPIO_NUM_33  // Servo PWM Signal (non inverting, outputs 5V when HIGH, pulls to GND when LOW)


 

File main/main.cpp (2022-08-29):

#include <stdio.h>

extern "C"
{
#include <esp_system.h>
#include <esp_event.h>
#include <nvs_flash.h>
#include "freertos/FreeRTOS.h"
#include "freertos/task.h"
#include "driver/gpio.h"
#include "esp_log.h"
#include "sdkconfig.h"
}

#include "gpio_evaluateSwitch.hpp"
#include "config.hpp"
#include "gate.hpp"
#include "control.hpp"

#include "buzzer.hpp"

static const char *TAG = "main";



//==================================
//===== statusReport function ======
//==================================
//function for debugging that prints several global variables and gpio states
//to get an overview of the current system state
uint32_t timestamp_debugOutput = esp_log_timestamp();
void statusReport(){
    
    ESP_LOGI(TAG, "============= STATUS REPORT =============");
    ESP_LOGI(TAG, "BUTTONS: S8 button_open=%d  |  S7 button_close=%d", buttonOpen.state, buttonClose.state);
    ESP_LOGI(TAG, "CONTROL: State=%s  |  count=%d  |  lastAction=%d", controlStateStr[(int)ctlState], countPressed, timestampLastAction);
    ESP_LOGI(TAG, "RIGHT GATE: State=%s  |  S1 open=%d  |  S2 closed=%d  |  K1 opening=  |  K2 closing=",
            gateStateStr[(int)gateRight.state], gpio_get_level(GPIO_B_RIGHT_OPEN), gpio_get_level(GPIO_B_RIGHT_CLOSED));
    ESP_LOGI(TAG, "LEFT GATE:  State=%s  |  S3 open=%d  |  S4 closed=%d  |  K1 opening=?  |  K2 closing=?",
            gateStateStr[(int)gateRight.state], gpio_get_level(GPIO_B_LEFT_OPEN), gpio_get_level(GPIO_B_LEFT_CLOSED));
    ESP_LOGI(TAG, "=========================================");
    timestamp_debugOutput = esp_log_timestamp();
}


//======================================
//============ buzzer task =============
//======================================
//TODO: move the task creation to buzzer class (buzzer.cpp)
//e.g. only have function buzzer.createTask() in app_main
void task_buzzer( void * pvParameters ){
    ESP_LOGI("task_buzzer", "Start of buzzer task...");
        //run function that waits for a beep events to arrive in the queue
        //and processes them
        buzzer.processQueue();
}



//=================================
//=========== app_main ============
//=================================
//main function that gets run at startup
extern "C" void app_main(void)
{
    //==============================
    //====== startup commands ======
    //==============================
    //commands run once at controller startup
    ESP_LOGI(TAG, "Start of main function...");

    //------------------------------
    //--- create task for buzzer ---
    //------------------------------
    xTaskCreate(&task_buzzer, "task_buzzer", 2048, NULL, 5, NULL);

    //beep at startup
    buzzer.beep(3, 50, 100);

    //-----------------------------
    //--------- variables ---------
    //-----------------------------
    //count for testing beep class
    //int count = 2;

    //----------------------------
    //--------- loglevel ---------
    //----------------------------
    esp_log_level_set("*", ESP_LOG_INFO);
    esp_log_level_set("buzzer", ESP_LOG_ERROR);
    esp_log_level_set("main", ESP_LOG_INFO);
    esp_log_level_set("control", ESP_LOG_INFO);
    esp_log_level_set("gate", ESP_LOG_INFO);


    //=============================
    //========= main loop =========
    //=============================
    while (1){
        vTaskDelay(10 / portTICK_PERIOD_MS); //slight delay is required otherwise watchdog will be triggered
        

        //-----------------------------
        //------- run functions -------
        //-----------------------------
        //periodicly run all functions required for controlling the gates

        //run handle function for evaluated switches
        //buttons
        buttonOpen.handle();
        buttonClose.handle();
        //remote
        remoteOpen.handle();
        remoteClose.handle();
        //TODO: declare and run these only where actually used to make use of events (not global)
        //note: the switch objects are declared in config.hpp and configured in config.cpp

        //run function that processes buttons and controls the gate
        control();

        //run handle function for gates
        gateRight.handle();
        gateLeft.handle();
        //note: gates are declared in config.hpp and configured in config.cpp


        //----------------------------
        //------- debug output -------
        //----------------------------
        //TODO: add logging and loglevel support in evaluated switch library to make the below code unnecessary
        //testing evaluated switch - log button events
        if (buttonOpen.risingEdge){
            ESP_LOGI(TAG, "== Button open pressed == - time Released: %d", buttonOpen.msReleased);
            //test beep class:
            //buzzer.beep(count, buttonOpen.msPressed, 500);
            //count++;
        }else if (buttonOpen.fallingEdge){
            ESP_LOGI(TAG, "== Button open released == - time Pressed: %d", buttonOpen.msPressed);
        }

        if (buttonClose.risingEdge){
            ESP_LOGI(TAG, "== Button close pressed == - time Released: %d", buttonClose.msReleased);
        }else if (buttonClose.fallingEdge){
            ESP_LOGI(TAG, "== Button close released == - time Pressed: %d", buttonClose.msPressed);
        }


        //testing remote receiver inputs  - log events
        if (remoteOpen.risingEdge){
            ESP_LOGW(TAG, "== Remote open on== - time Released: %d", remoteOpen.msReleased);
            //buzzer.beep(1, 300, 0);
        }else if (remoteOpen.fallingEdge){
            ESP_LOGI(TAG, "== Remote open off == - time Pressed: %d", remoteOpen.msPressed);
        }

        if (remoteClose.risingEdge){
            ESP_LOGW(TAG, "== Remote close high == - time Released: %d", remoteClose.msReleased);
            //buzzer.beep(2, 100, 0);
        }else if (remoteClose.fallingEdge){
            ESP_LOGI(TAG, "== Remote close low == - time Pressed: %d", remoteClose.msPressed);
        }




        //show debug output in certain time intervals
        if (esp_log_timestamp() - timestamp_debugOutput > 5000){
                    //statusReport();
        }



    }//end while(1)

}//end app_main

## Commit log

2022-05-27 init (esp-idf sample_project)
    copy sample project from esp-idf
2022-05-27 README: Remove sample, Add pin assignment
2022-05-27 Create config.hpp, Add all gpio pins
    Create separate file for configuration
    Add all currently used gpio pins to this file
    Modify main.cpp to use those variables
2022-05-27 Add function 'statusReport'
    Add function statusReport in main.cpp
    Currently is run every 5s and displays the current state of the buttons
    and switches
2022-05-28 Create component gpio_evaluateSwitch
    - Copy library written for avr projects
    - Modify files to work with esp32 instead of avr
    - create component for esp-idf (CMakeLists.txt)
    Note this broke the `make` command when including this library " fatal
    error: gpio_evaluateSwitch.hpp: No such file or directory"
    However `idf.py` works fine
    [gpio_evaluateSwitch.cpp]
2022-05-28 Use evaluatedSwitch class for Open/Close buttons
    - create objects for the two switches in config.hpp (so they are
    globally available)
    - main.cpp: add call off handle functions in the main loop
    - main.cpp: change status report function to use evaluated object for
    start/stop buttons instead of reading gpio
    - main.cpp: add log output to print button events for testing the new
    feature
    - note in readme that make commands no longer works atm (use idf.py instead see previous commit)
    [config.hpp, main.cpp]
2022-05-28 Outsource gate class (gate.cpp/hpp, config.cpp)
    - move gate class and declaration from main.cpp to gate.hpp
    - move gate class definition from main.cpp to gate.cpp
    - create constructor for gate object with configuration instead of
    accessing the variables directly
    - move declaration of all objects to config.hpp
    - move all config definitions to config.cpp (instead of all in hpp) this
    makes it possible to include the header files in multiple different
    files without redefinition errors
    [config.cpp, config.hpp, gate.cpp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]
2022-05-28 Create control.hpp - control gate with buttons
    - Create function 'control' in separate file control.hpp
    - Add control state and information to status report in main.cpp
    - increase status report interval
    - add gate.setDuration function to gate.cpp (was not defined)
2022-05-29 Add logging output, swap buttons, add name
    - add logging output to all functions with different loglevels
    - add name string to gate class
    - add name to object initialization in config
    - swap gpio pin of buttons
    [config.cpp, config.hpp, gate.cpp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]
2022-05-29 Fix random outputs bug (direction definition)
    All outputs were defined as inputs (direction definition had no effect)
    thus the mosfets switched randomly (floating)
    - add pad select function before each set_direction function in gate.cpp
    and gpio_evaluateSwitch.cpp
    - add beep at start of main functon
    - add log output in evaluateswitch.cpp
    [gate.cpp, gpio_evaluateSwitch.cpp, main.cpp]
2022-05-29 Fix 'open completely', Adjust durations
    - fix bug where 'open completely' was hard to achieve (button had to be
    pressed at the exact right time). Now the open button has to be
    pressed continuously for more than 800ms to trigger 'open completely'
    event
    - decreased duration of 'open slightly' to 1.2s according to old project
    - adjust lastaction timeout
    - add feature to stop gates with close button during 'wait for input'
2022-05-30 Create buzzer_t class (buzzer.hpp/cpp)
    Crate class for controlling the buzzer with the following features:
    - is run in another task
    - queues up beep commands (if another beep command is run while a
    previous one is still processing)
    Steps in this commit:
    - create files buzzer.cpp and .hpp with the new class
    - add buzzer.cpp to CmakeLists
    - add buzzer instance to config.hpp define/configure in config.cpp so
    that buzzer object is globally available
    - add creation of task to main.cpp
    - replace previous definition and 3x beeping of buzzer gpio pin at startup
    with the new beep function
    - add code in main loop to test beep object (commented out)
    - slightly fix comments in main.cpp
    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
    [buzzer.cpp, config.cpp, config.hpp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]
2022-05-30 Add beeping, Change gate::stop(): add stopReason
    - use buzzer object in gate.cpp and control.hpp for signaling certain
    events
    - add stopReason enum to gate::stop function. This reduces duplicate
    code for logging and beeping
    [gate.cpp, gate.hpp]
2022-05-30 Add inputs of remote control (testing)
    - Add 2 inputs of remote control as evaluatedSwitch objects
    - Add test output in main.cpp to test whether the signal is detected,
    since receiver is connected to adc input
2022-05-30 Add functionality to remote control inputs
    - Invert switches (noticed while testing that relays switch to gnd,
    pulldown soldered on pcb)
    - Add code for the new inputs from remote control to control.hpp
    - open gate when remoteOpen rising edge
    - close gate when remoteClose rising edge
    - stop gates when any remote input (or any button pressed)
    [config.cpp]
2022-05-30 Fix 'open slightly' duration, Decrease beeps
    - fix open slightly duration (was increased even when only pressed once,
    since countPressed started at 1)
    - make beeps even shorter
    [gate.cpp, main.cpp]
2022-08-27 Add 'WAITING' state - wait for standstill
    When starting the gate while it is moving (e.g. immediately restart after stop) the motors may start
    rotating in the wrong direction.
    This results in a fatal crash - gate moves to other than intended limit
    switch and will not stop before timeout.
    -> Add delay between stop and IDLE, thus preventing an immediate re-start
    [untested]
    [config.cpp, gate.cpp, gate.hpp]
2022-08-27 Add handling of case 'wrong motor direction'
    In addition to prevent start in wrong direction in the first place (see
    last commit), add handling of case when ending up at wrong limit switch
    again.
    see updated function diagram
    quite large change to statemachine:
    - rename states
    - add new states
    - add new function retry()
    [config.cpp, gate.cpp, gate.hpp]
2022-08-27 Fix bug stuck in 'WAIT_RETRY', Adjust durations, ctl
    - fix missing state change in WAIT_RETRY
    - adjust durations in config
    - optimize control to only accept commands when gates are ready
    - add some logging output for debugging
    [config.cpp, gate.cpp]
2024-10-27 Add VFD datasheets + modbus test (from cable-length-cutter repo)
2024-12-23 Add assets: gear 3d-models, labels, schema, overview.pdf
    [spur-gear_m4_z12-v3.scad, spur-gear_m4_z12-v3.stl, spur-gear_m4_z24-v4.scad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]
2024-12-23 Add RS485 test: Turn on vfd + set freq via modbus - works
    Note: hardware setup: MAX485 supplied with 5V
    with custom mosfet level shifters
    -> DIR and TX pins are inverted in software
2024-12-23 Add support for reading registers (reading voltage, current, temperature)
2024-12-24 Create kicad project pcb_v2.0-isolated-gate-control - Add esp32, RS485, digital-in, supply
    [pcb_v2.0-isolated-gate-control.kicad_pcb, pcb_v2.0-isolated-gate-control.kicad_sch]
2024-12-24 pcb: outsrc isolated-dig-in, assign pins, Add supply, 12V out, servo-pwm
    [isolated-digital-input_sw-to-gnd.kicad_sch, pcb_v2.0-isolated-gate-control.kicad_sch]
2024-12-25 pcb: Add Relays, mosfet-out, terminals, Fix RS485 isolation
    [isolated-digital-input_sw-to-gnd.kicad_sch, pcb_v2.0-isolated-gate-control.kicad_pcb, pcb_v2.0-isolated-gate-control.kicad_sch]
2024-12-25 pcb: Optinmize/protect PWM out, Start Layout (arrange as schematic)
    [pcb_v2.0-isolated-gate-control.kicad_pcb, pcb_v2.0-isolated-gate-control.kicad_sch]
2024-12-25 pcb: change footprints + arrange groups individually for saving space
    [isolated-digital-input_sw-to-gnd.kicad_sch, pcb_v2.0-isolated-gate-control.kicad_pcb, pcb_v2.0-isolated-gate-control.kicad_sch]
2024-12-25 pcb: arrange almost all groups inside 100x165 pcb
    [pcb_v2.0-isolated-gate-control.kicad_pcb, pcb_v2.0-isolated-gate-control.kicad_sch]
2024-12-26 pcb: Re-assign FP, Optimize arrangement, Proof-of-concept routing
    [pcb_v2.0-isolated-gate-control.kicad_pcb, pcb_v2.0-isolated-gate-control.kicad_sch]
2024-12-27 pcb: remap gpio-pins, finish proof-of-concept routing (to evaluate arrangement)
    [pcb_v2.0-isolated-gate-control.kicad_pcb, pcb_v2.0-isolated-gate-control.kicad_sch]
2024-12-28 pcb: routing complete (DRC pass)
    [pcb_v2.0-isolated-gate-control.kicad_pcb, pcb_v2.0-isolated-gate-control.kicad_sch]
2024-12-28 pcb: Add text, testpoints, mounting-holes
    [pcb_v2.0-isolated-gate-control.kicad_pcb, pcb_v2.0-isolated-gate-control.kicad_sch]
2024-12-29 pcb: Add NOT-Gate (optocouplers off in idle), Replace ULN28 with 7Ch
    [pcb_v2.0-isolated-gate-control.kicad_pcb, pcb_v2.0-isolated-gate-control.kicad_sch]
2024-12-29 pcb: Invert optocoupler-GPIO connection (high=output on), Layout adjusted (DRC pass)
    [pcb_v2.0-isolated-gate-control.kicad_pcb, pcb_v2.0-isolated-gate-control.kicad_sch]
2024-12-31 pcb: Cleanup Schematic, arrange, replace legacy-symbols, optimize for ERC pass
    [isolated-digital-input_sw-to-gnd.kicad_sch, pcb_v2.0-isolated-gate-control.kicad_pcb, pcb_v2.0-isolated-gate-control.kicad_sch]
2024-12-31 Add pcb2gcode configs + script (copied from other project)
2025-01-01 pcb: finish todos, Fix esp32 power issues, document tests, dualType C footprint
    [isolated-digital-input_sw-to-gnd.kicad_sch, pcb_v2.0-isolated-gate-control.kicad_pcb, pcb_v2.0-isolated-gate-control.kicad_sch]
2025-01-01 Extend pcb2gcode script: add pass (mill away copper), Add gcode - [MILLED PCB]
2025-01-02 pcb: Arrange silk/fab text, Mark front-solder, Add schematic+layout export
    [isolated-digital-input_sw-to-gnd.kicad_sch, pcb_v2.0-isolated-gate-control.kicad_pcb, pcb_v2.0-isolated-gate-control.kicad_sch]
2025-01-05 pcb: fix minor layout issues (missing text, spacing)
    [pcb_v2.0-isolated-gate-control.kicad_pcb]
2025-01-05 fw: Fix pin-assignment, Invert IO passthrough level
    [config.h]
2025-01-06 fw: Fix invalid UART signal inversion, Re-assign pins
    [config.h, modbus.c]
2025-01-06 pcb: Add Changelog, Note about GPIO-2 input issue
    [pcb_v2.0-isolated-gate-control.kicad_pcb, pcb_v2.0-isolated-gate-control.kicad_sch]
2025-01-26 Add class VFD, main: switch to c++, modbus: use esp-error-codes
    Add class VFD for abstracting the RS485 communication
    Test two class instances in main loop, test with one vfd success
    [config.h, main.cpp, modbus.c]
2025-02-08 Add direction option to VFD, Revert pin assignment deletion, Add Buzzer class
    [buzzer.cpp, config.h]
2025-02-08 Rework gate class (compiles, basic logging test success)
    [gate.cpp, gate.hpp, main.cpp]
2025-02-09 Add option to invert limit-switches, Optimize logging, variable-names, structure
    [gate.cpp, gate.hpp, main.cpp]
2025-02-19 Add control.cpp for controlling 2 gates with buttons [WIP]
    note: no new features, rewrite of V1
    WIP: does not compile yet
2025-02-21 Add workaround for errors when using low baudrate (add delay)
    [modbus.c]
2025-02-22 Increase delay, logging, baudrate 9600 - gate not closing, stop error G2
    [config.h, gate.cpp, gate.hpp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]
2025-02-22 Run VFD test only (VFD1 reverse) - VFD ACK but not starting
    [main.cpp]
2025-02-22 Doc: Add VFD parameters, connection-plan, Update terminal-labels
    [terminal-labels.ods]
2025-02-22 Add logging of VFD current when closing
2025-02-22 Add workaround for VFD not stopping, Adjust timeouts/delays (gate, modbus)
    Sending dummy register read request first then actual stop command.
    Dummy request often fails but stopping always works now!
    [control.cpp, gate.hpp, main.cpp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]
2025-02-24 Change addresses for VFDs 1 / 2 to 11 / 77, Minor Optimizations (beep, button)
2025-02-25 Add vfd current monitoring (stop closing when threshold exceeded), beep at limit change
2025-02-26 Adjust parameters: freq 50Hz, switch-press-time, move-durations, timeout, loglevel
2025-02-26 Gate: Fix inf. start loop on VFD com fail, Add support for Fault-LED
    [control.cpp, gate.cpp, main.cpp]
2025-03-24 Add light-barrier gpio-pin to controlConfig (pass to task)
2025-03-27 Add detailed wiring-plan of all components (drawio and exports)
2025-03-30 Increase VFD turn-off-timeout (1h -> 2.5h), Fix button bounce - Increase button deadtime (20->40ms)
    [gate.cpp, gate.hpp]
2025-04-03 Revert vfd-startup-delay, Increase turn-off-timeout to 3h
    [gate.hpp]
2025-04-13 Add fault-led blinking in MOVEMENT_PAUSED (waiting for barrier)
2025-04-17 Adjust thresholds, Fix led-blinking and beeping (works as intended)
    [control.cpp, gate.cpp, main.cpp]
2025-04-18 Update connection+wiring plan (redraw switches, flash note)
2025-04-19 Add debug beep / led-passthrough for barrier, Add Beep at close start
2025-04-20 Fix remote-control close button ignoring barrier check
    [control.cpp]
